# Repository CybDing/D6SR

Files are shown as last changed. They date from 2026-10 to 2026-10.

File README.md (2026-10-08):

<div align="center">

**English** | [简体中文](README.zh-CN.md)

# D6SR: A Mechanically Decoupled Six-Axis Spherical Rolling Robot

**Design and Control of D6SR: A Mechanically Decoupled Six-Axis Spherical Rolling Robot for Stable Propeller-Driven Rolling**<br>
IROS 2026

Leqi Ding\*, Xijian Deng\*, Jiayi Chen, Jin Yang, Ping Wei<br>
Xi'an Jiaotong University · \*equal contribution

Paper: coming soon · [License: Apache-2.0](LICENSE)

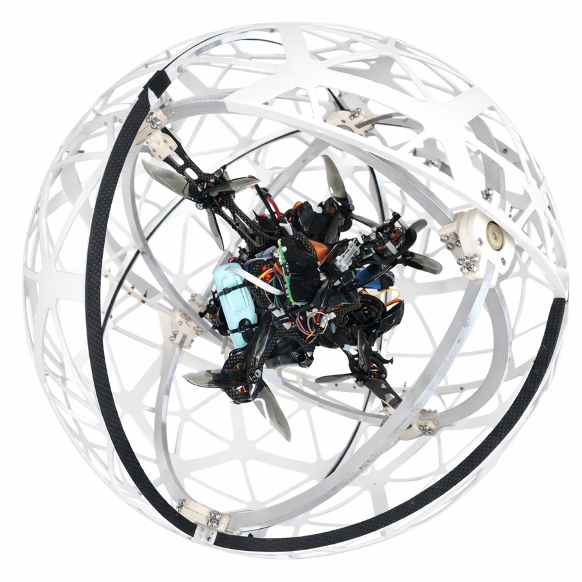
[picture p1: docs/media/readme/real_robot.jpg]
D6SR prototype


</div>

D6SR is a propeller-driven spherical robot. Six reversible propellers are mounted on an inner body, and a three-DoF gimbal decouples that body from the passive rolling shell. While the shell rolls, the inner body stays level, so every thrust direction stays fixed in the world frame and the motors do not have to keep reversing. A cascaded PID controller holds the inner-body attitude. On top of it, a residual reinforcement-learning policy, trained in simulation on IMU-only observations, adds corrective torque on rough terrain.

<p align="center">
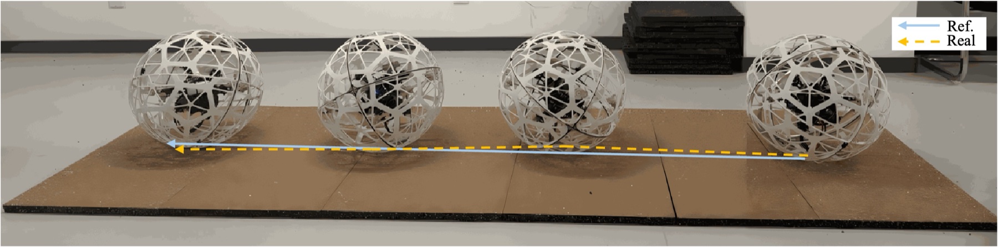
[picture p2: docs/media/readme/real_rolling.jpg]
Hardware rolling experiment
  <br>
  <em>Hardware rolling experiment: the robot keeps a straight heading (blue: reference, yellow: actual).</em>
</p>

## Contents

- [Highlights](#highlights)
- [Hardware](#hardware)
- [Method](#method)
- [Results](#results)
- [Repository structure](#repository-structure)
- [Getting started](#getting-started)
- [Reproducing the paper](#reproducing-the-paper)
- [Serial protocol](#serial-protocol)
- [Citation](#citation)
- [License](#license)

## Highlights

- **Mechanical decoupling.** A three-DoF gimbal separates shell rotation from the propulsion module, so thrust directions stay constant during rolling.
- **Tri-orthogonal six-propeller propulsion.** Three orthogonal pairs of reversible propellers can generate an arbitrary body wrench without dedicated drive motors.
- **Cascaded PID + residual RL.** A Soft Actor-Critic policy outputs only a residual torque on top of the PID baseline.
- **Calibrated simulation.** The MuJoCo model is calibrated to the prototype (per-propeller thrust, bearing friction, sensor noise, loop delay, thrust lag). The repository includes the trained policy and the scripts that regenerate every simulation figure in the paper.

## Hardware

<p align="center">
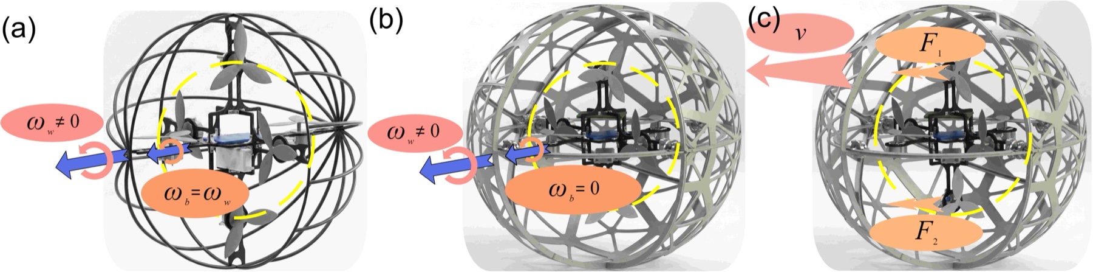
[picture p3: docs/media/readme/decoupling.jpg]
Decoupling principle
  <br>
  <em>(a) Without decoupling the inner body rotates with the shell. (b) With the gimbal it stays still while the shell rolls. (c) Thrusts F<sub>1</sub>, F<sub>2</sub> therefore stay fixed in the world frame and drive the robot at velocity v.</em>
</p>

| Item | Specification |
|---|---|
| Outer diameter / total mass | 460 mm / 2.78 kg |
| Propulsion | 6 reversible brushless motors with bidirectional ESCs, 14.7 N max thrust each |
| Controller | STM32F407VET6 (libopencm3 + FreeRTOS), cascaded PID at 100 Hz |
| Companion computer | Raspberry Pi 4B (serial bridge, logging, MQTT) |
| Attitude sensor | IMU over UART, 200 Hz |
| Link | UART 115200 bps, 8N1 |

<details>
<summary>Mechanical design</summary>
<p align="center">
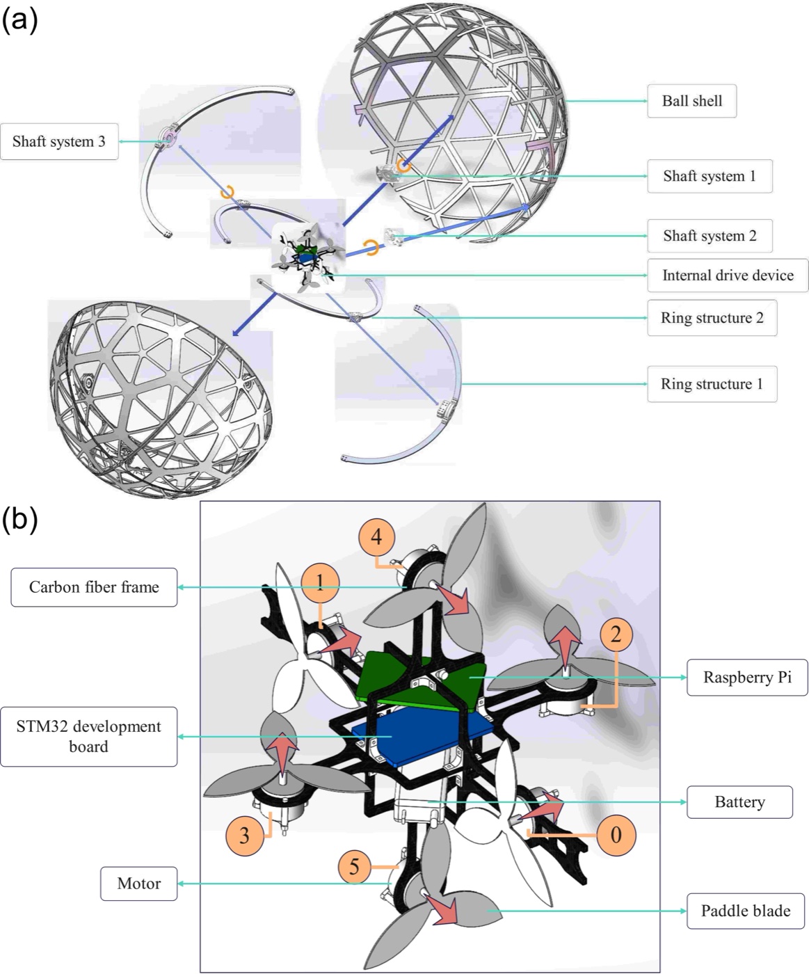
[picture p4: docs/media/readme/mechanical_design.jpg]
Mechanical design
  <br>
  <em>(a) Exploded view of the outer shell and the gimbal-based inner module. (b) Integrated six-actuator propulsion and control platform.</em>
</p>
</details>

## Method

**Attitude control.** Roll, pitch and yaw of the inner body are regulated by three cascaded PID loops: the outer loop maps angle to angular-rate setpoint, the inner loop maps rate to torque. The firmware (`stm32/cascaded_pid.c`) and the simulator (`simulation/mujoco_sim/control/cascaded_pid.py`) implement the same controller.

**Motion control.** The desired planar acceleration is rotated from the world frame into the body frame using the measured yaw, then tracked by a velocity PID.

**Control allocation.** Motors M0/M1, M2/M3 and M4/M5 form the yaw, roll and pitch pairs. The commanded wrench is mapped to signed, normalized motor thrusts and clipped to [-1, 1]. In the code and on the robot, the attitude torque of each pair is applied by raising the thrust of one motor only, rather than pushing the two motors in opposite directions. This engineering choice avoids reversing the motors just to make small attitude corrections.

**Residual RL.** The policy adds a bounded residual torque to the PID output. Each observation frame is 11-dimensional (sin/cos of roll, pitch and yaw; body rates; velocity-tracking error), and the policy input stacks the last four frames. It was trained with SAC for 400k steps, with domain randomization over gimbal initial angles, rolling friction, target velocity and terrain roughness (≤ 0.2). Full hyperparameters are in [docs/figure_reproduction.md](docs/figure_reproduction.md).

## Results

All simulation figures below come from the scripts in this repository with the released policy. PID gains were tuned, and the policy was trained, only on terrain roughness ≤ 0.2.

| Task | No attitude control | Cascaded PID | PID + residual RL |
|---|---|---|---|
| Circle, R = 10 m, 0.5 m/s, roughness 0.2 | flips, mean error 24.35 m | — | **0.55 m, no flip** |
| Straight line, 1.0 m/s, roughness 0.3: flips in 5 runs | 5 / 5 | 3 / 5 | **0 / 5** |

<table>
  <tr>
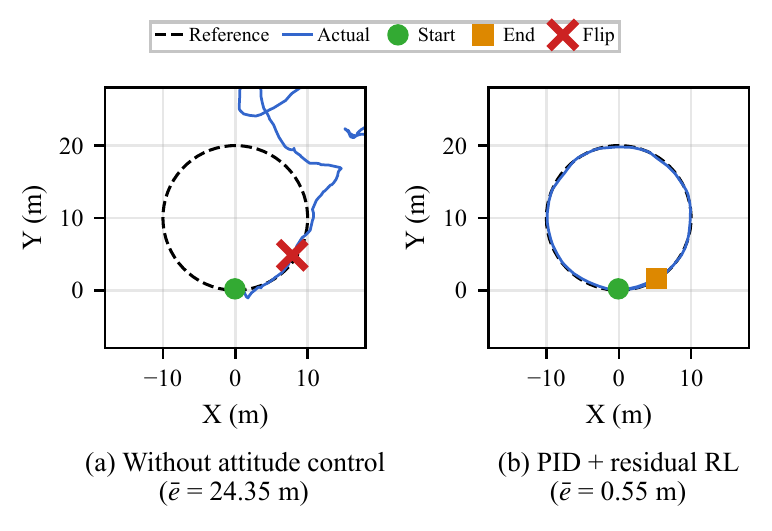
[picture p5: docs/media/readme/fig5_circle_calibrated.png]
Circle tracking
    <td align="center" width="50%"><br><em>Circular rolling on roughness 0.2.</em></td>
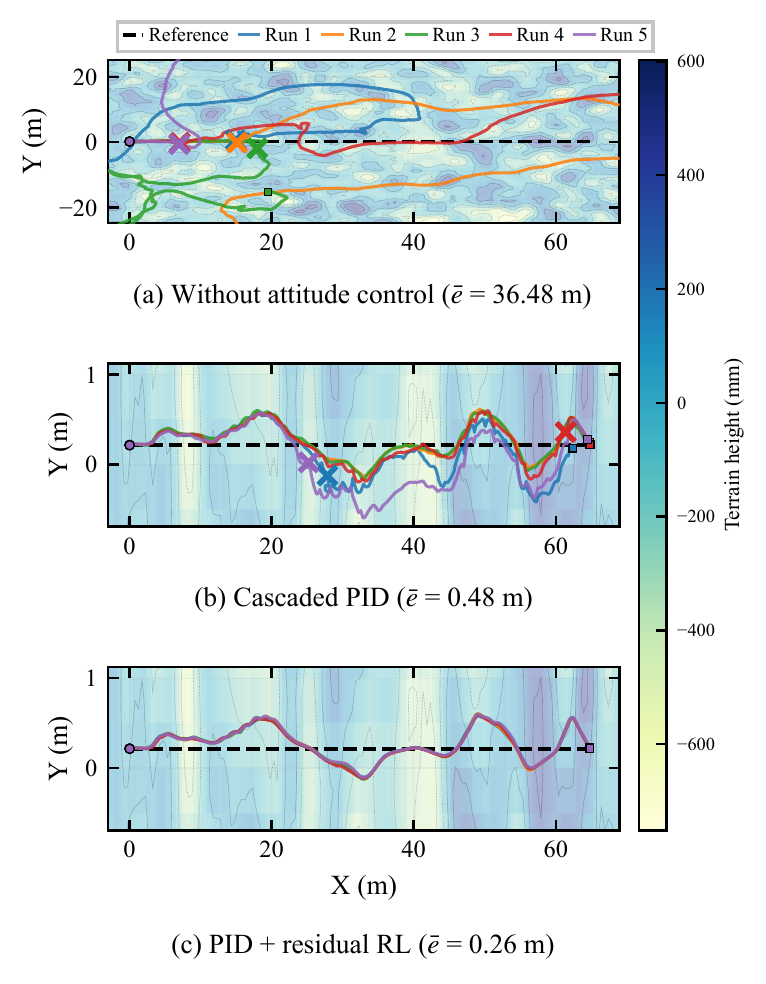
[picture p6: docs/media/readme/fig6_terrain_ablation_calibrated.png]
Straight-line terrain test
    <td align="center" width="50%"><br><em>Straight-line rolling on roughness 0.3, five runs per controller. × marks a flip.</em></td>
  </tr>
  <tr>
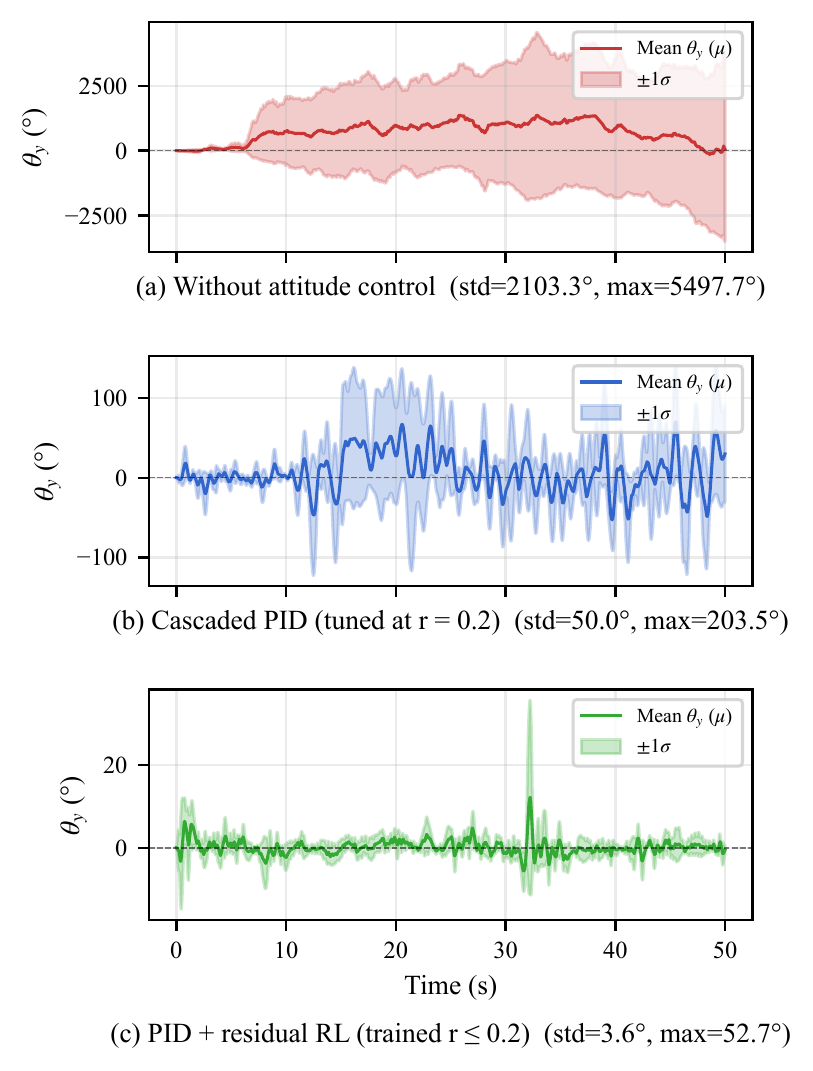
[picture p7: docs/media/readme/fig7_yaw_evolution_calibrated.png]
Yaw evolution
    <td align="center"><br><em>Inner-body yaw on roughness 0.3 (mean ± 1σ over 4 runs).</em></td>
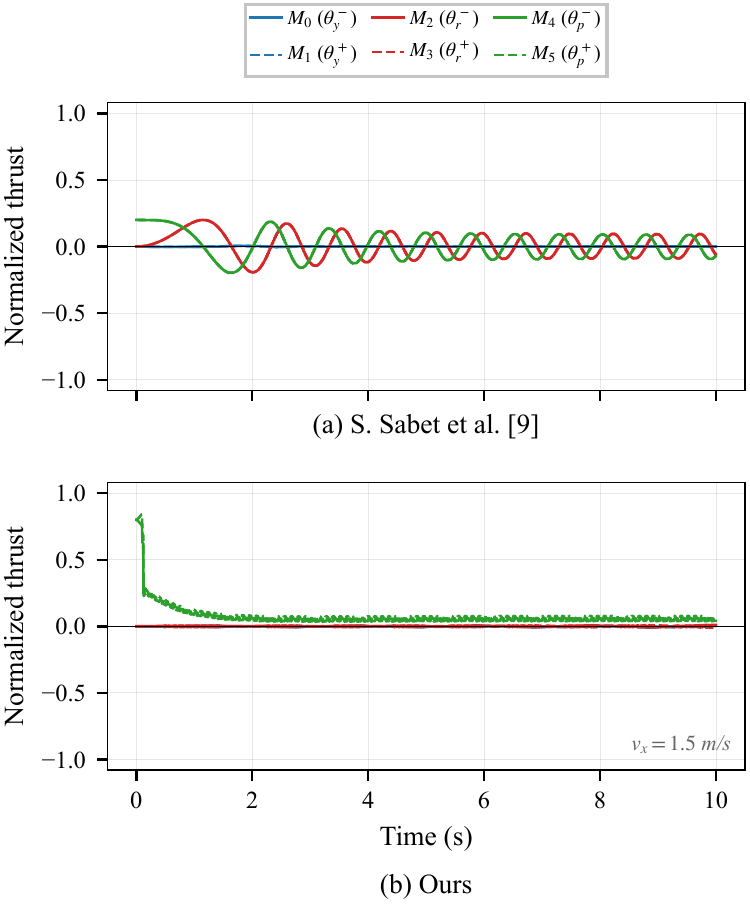
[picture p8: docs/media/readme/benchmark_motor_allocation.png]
Motor allocation
    <td align="center"><br><em>Motor commands at v<sub>x</sub> = 1.5 m/s: (a) shell-fixed propellers (Rollocopter, Sabet et al.) keep reallocating thrust; (b) D6SR holds nearly constant thrust.</em></td>
  </tr>
</table>

<p align="center">
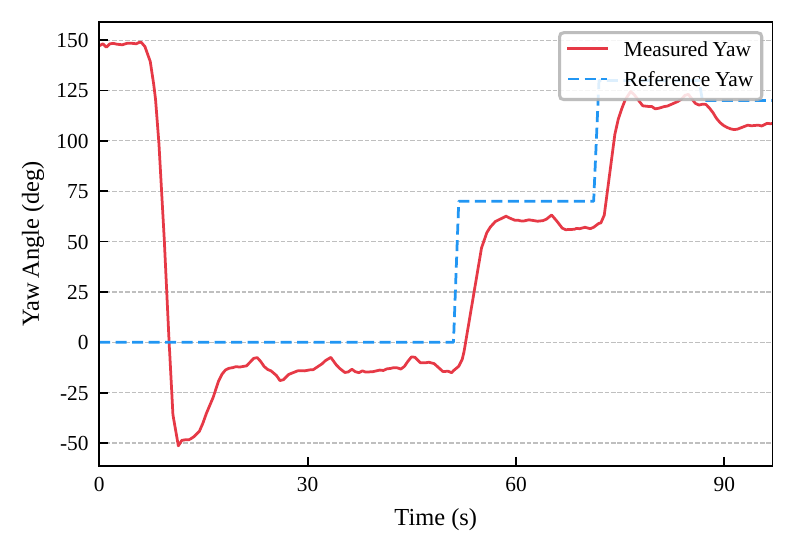
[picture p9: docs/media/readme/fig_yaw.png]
Hardware yaw step response
  <br>
  <em>Hardware: yaw stabilization during rolling under step reference commands.</em>
</p>

## Repository structure

```
D6SR/
├── stm32/                     # STM32F407 firmware: FreeRTOS tasks, cascaded PID, PWM, IMU, UART
├── raspberry_pi/              # host program: serial bridge, MQTT, logging and plotting
├── simulation/
│   ├── mujoco_sim/
│   │   ├── simulation.py      # RobotSimulation: model build, contact, rolling friction, IMU
│   │   ├── config/            # robot_params.yaml, calibrated plant, tuned PID gains
│   │   ├── control/           # cascaded PID, allocation, baseline controller, trajectories
│   │   ├── rl/                # Gym-style env, SAC, residual training; released policy in rl/checkpoints/
│   │   ├── analysis/          # scripts for paper Figs. 5-7 and PID tuning
│   │   ├── benchmark_*.py     # benchmark scripts (benchmark_baseline.py -> Fig. 8)
│   │   └── video/             # scenario recording
│   ├── robot_v0/, robot_v1/   # URDF + meshes (v0: shell-fixed baseline, v1: D6SR)
├── docs/                      # figure_reproduction.md, figures
├── data/                      # hardware yaw data behind Fig. 9
├── tools/                     # yaw PID tuning and figure-data utilities
├── libopencm3/                # submodule
└── rtos/FreeRTOS-Kernel/      # submodule
```

## Getting started

### Simulation

Python ≥ 3.9:

```bash
git clone --recursive https://github.com/CybDing/D6SR.git
cd D6SR/simulation/mujoco_sim
pip install mujoco numpy scipy matplotlib pyyaml torch

# baseline attitude stabilization + velocity drive (headless, with plots)
python control/run_baseline.py --plot --drive-x 0.5
```

Run every script from `simulation/mujoco_sim/`. On macOS, the interactive viewer needs `mjpython` (e.g. `mjpython control/run_baseline.py --no-headless`). Physics parameters live in `config/robot_params.yaml`; after editing them, regenerate the MJCF with `python robot_loader.py`.

### Firmware

Requirements: `arm-none-eabi-gcc` ≥ 10, `make`, `st-flash` (stlink-tools).

```bash
git submodule update --init --recursive    # if not cloned with --recursive
make -C libopencm3 TARGETS=stm32/f4         # once

cd stm32
make                 # build
make f407-program    # clean rebuild + flash
make monitor         # serial console (minicom, /dev/ttyUSB0, 115200)
```

Pin, timer and UART assignments are in `stm32/pin_config.h`.

### Host (Raspberry Pi)

```bash
cd raspberry_pi
pip3 install -r requirements.txt
python3 main.py          # serial + MQTT + logging + plotting
python3 simple_test.py   # connectivity check
```

## Reproducing the paper

Run from `simulation/mujoco_sim/` with `P=rl/checkpoints/calib_v7b_nojoint_fs4/best.pt`:

| Figure | Command |
|---|---|
| Fig. 5 circle | `python analysis/fig_circle.py --policy $P` |
| Fig. 6 terrain | `python analysis/fig6_ablation.py --policy $P` |
| Fig. 7 yaw | `python analysis/fig_paper_yaw.py --policy $P` |
| Fig. 8 allocation | `python benchmark_baseline.py --no-rl` |

Seeds are fixed, so the reruns reproduce the published numbers exactly. [docs/figure_reproduction.md](docs/figure_reproduction.md) (in Chinese) lists the expected values for each figure, the PID-tuning and RL-training commands, a table mapping the paper's hyperparameters to code arguments, and the places where the implementation differs from the paper's wording. Fig. 9 is a hardware experiment; its data, recovered from the vector figure, is in `data/fig9_yaw_hardware.csv`.

## Serial protocol

Frames are `CMD:DATA1,DATA2,...\n` over UART at 115200 bps, 8N1.

| Command | Format | Direction | Meaning |
|---|---|---|---|
| `PWM` | `PWM:m0,m1,m2,m3,m4,m5` | Pi → STM32 | set the six motor pulses, 1000–2000 µs, 1500 = neutral |
| `PID` | `PID:kp,ki,kd` | Pi → STM32 | update PID gains |
| `IMU` | `IMU` → `IMU:ax,ay,az,gx,gy,gz,roll,pitch,yaw` | both | request / return IMU data |
| `STATUS` | `STATUS` → `STATUS:motor,imu,pid` | both | subsystem status |
| `DEBUG` | `DEBUG:message` | STM32 → Pi | debug message |

## Citation

```bibtex
@inproceedings{ding2026d6sr,
  title     = {Design and Control of {D6SR}: A Mechanically Decoupled Six-Axis Spherical Rolling Robot for Stable Propeller-Driven Rolling},
  author    = {Ding, Leqi and Deng, Xijian and Chen, Jiayi and Yang, Jin and Wei, Ping},
  booktitle = {2026 IEEE/RSJ International Conference on Intelligent Robots and Systems (IROS)},
  year      = {2026}
}
```

## License

The code in this repository is released under the [Apache License 2.0](LICENSE). The third-party submodules keep their own licenses: `libopencm3/` (LGPL-3.0) and `rtos/FreeRTOS-Kernel/` (MIT).

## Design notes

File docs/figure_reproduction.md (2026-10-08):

# 论文插图复现说明

记录论文 *Design and Control of D6SR* 中图 5–9 的生成方式：用哪个脚本、哪个 checkpoint、期望得到什么数值。所有仿真图的随机种子均已固定，因此重跑应当逐位复现，下表的「校验数值」就是用来确认这一点的——跑完对不上，说明参数或 checkpoint 用错了。

## 通用前提

- 全部命令从 `simulation/mujoco_sim/` 目录执行（相对路径依赖此工作目录）。
- 无需 `mjpython`：这些都是 headless 出图，用 `python` 即可（`mjpython` 只在需要交互式 viewer 时才必要）。
- 物理参数来自 `config/robot_params.yaml`，PID 增益来自 `config/tuned_gains_calibrated.json`（脚本默认值），均无需手动指定。
- 图 5/6/7 的排版（字体、子图标签）统一由 `simulation/mujoco_sim/paper_style.py` 提供，不要在各脚本里另写 rcParams。

## 图 5–8

| 图 | 命令（在 `simulation/mujoco_sim/` 下） | 输出 | 校验数值 |
|---|---|---|---|
| 5 | `python analysis/fig_circle.py --policy rl/checkpoints/calib_v7b_nojoint_fs4/best.pt` | `docs/media/fig5_circle_calibrated.pdf` | (a) mean err 24.35 m；(b) 0.55 m |
| 6 | `python analysis/fig6_ablation.py --policy rl/checkpoints/calib_v7b_nojoint_fs4/best.pt` | `docs/media/fig6_terrain_ablation_calibrated.pdf` | tier means 36.48 / 0.48 / 0.26 m |
| 7 | `python analysis/fig_paper_yaw.py --policy rl/checkpoints/calib_v7b_nojoint_fs4/best.pt` | `docs/media/fig7_yaw_evolution_calibrated.pdf` | (a) std 2103.3°；(b) std 50.0°；(c) std 3.6°, max 52.7° |
| 8 | `python benchmark_baseline.py --no-rl` | 见下方「图 8 的额外拷贝步骤」 | V0 travel +10.96 m；V1 travel +14.79 m |

### 图 7 的 policy 选择（重要）

图 5、6、7 **统一使用 `calib_v7b_nojoint_fs4`**。

早期提交的图 7 用的是 `calib_v6_fs4`，(c) 档得到 std = 4.3°、max = 44.4°；换成与图 5/6 相同的 `calib_v7b_nojoint_fs4` 后为 **std = 3.6°、max = 52.7°**。三张图现已统一到同一个 policy，论文正文中引用图 7 的数值需与此一致。

注意 (a)、(b) 两档不含 RL，与 policy 无关，无论用哪个 checkpoint 都复现为 std 2103.3° / 50.0°。**因此 policy 用错只会在 (c) 档暴露**，(a)(b) 对得上并不能说明命令正确。

### 图 8 的额外拷贝步骤

`benchmark_baseline.py` 把 PDF 写到脚本自身目录，而 `.gitignore` 忽略 `*.pdf`、只放行 `docs/media/**`，所以纳入版本管理的是 `docs/media/` 下那一份，需手动拷贝：

```bash
python benchmark_baseline.py --no-rl
cp benchmark_motor_allocation.pdf ../../docs/media/benchmark_motor_allocation.pdf
```

`--no-rl` 决定了图中只有 (a)、(b) 两个面板；去掉该参数会额外生成 PID-only 与 PID+RL 面板。

## 图 9（硬件）——不可重跑

图 9 是实机 yaw 阶跃响应，不是仿真结果，仓库中没有生成它的脚本。

**原始树莓派日志从未落盘**：`raspberry_pi/main.py` 的 `_plot_yaw_cascaded()` 只调用 `plt.savefig` 输出 PNG 到 `raspberry_pi/plots/`（该目录只存在于树莓派上），`data_dict` 中的数组从未序列化，git 也从未跟踪过。因此不存在可供找回的日志，重跑也需要实体机器人。

现存物：

- `docs/media/fig_yaw.pdf` —— 图 9 本体（矢量 PDF，投稿时所用）。
- `data/fig9_yaw_hardware.csv` —— 从该 PDF 中还原出的数据，156 行 `time_s, measured_yaw_deg, reference_yaw_deg`。
- `tools/extract_fig_yaw_data.py` —— 还原脚本，可重跑复核：

```bash
python tools/extract_fig_yaw_data.py
```

还原是**精确复原而非估读**：坐标轴刻度给出闭式线性映射（残差 ~1e-7 pt），并有两个独立校验位——参考阶跃还原为精确整数（0 → 70 → 130 → 120 度），156 个测量点全部落在 0.1° 的 IMU 网格上（偏差 ~1e-5）。数值已 snap 回上述网格以消除 PDF 六位小数的往返误差。

两点需知：

- 参考信号在 t ≈ 72–86 s 有一档 **130°**，在原图中被图例框完全遮挡，肉眼不可见；矢量还原把它取了出来。实际是四档而非三档。
- 时间戳为不规则墙钟时间（中位 0.51 s），且 matplotlib 的 path-simplification 在当年渲染时丢弃了约 2% 的近似共线采样点——这部分 PDF 里根本没有，无法恢复。故该 CSV 是**图上所绘的曲线**，而非完整原始日志。

## 控制器与训练配置（对照论文 Table I / II）

### 仿真平台（论文 Table I）

| 论文参数 | 值 | 代码位置 |
|---|---|---|
| MuJoCo timestep | 0.001 s | `config/robot_params.yaml` |
| 控制频率（PID / RL） | 50 Hz | `SphericalRobotEnv(pid_rate=50)`，每个控制周期 20 个物理步 |
| 滚动摩擦 μ_roll | 0.01 | `SphericalRobotEnv(mu_roll=0.01)` |
| 单桨最大推力 | 14.7 N | `config/realistic_config.json` → `force_max` |
| 总质量 | 2.78 kg | `realistic_config.json` 的 `mass_overrides`（仿真内合计 2.785 kg） |
| 轴承摩擦 | 0.01 N·m | `realistic_config.json` → `joint_frictionloss`（另有 `joint_damping` 0.002） |
| 姿态 / 陀螺噪声 | 0.5° / 0.02 rad/s | realism pack，`--realism` |
| 控制回路延迟 | 20 ms（一个周期） | realism pack，`imu_delay_steps=1` |
| 推力一阶滞后 | 80 ms | realism pack，`thrust_tau=0.08` |

### PID 整定

`config/tuned_gains_calibrated.json` 是在标定后的 plant 上、开启 realism、r = 0.2 地形下用坐标下降整定得到的增益，图 5–7 与 RL 训练都使用它：

```bash
python analysis/tune_pid.py --realism --roughness 0.2 --out config/tuned_gains_calibrated.json
```

### 残差 RL 训练（论文 Table II）

论文所用 policy 为 `rl/checkpoints/calib_v7b_nojoint_fs4/best.pt`（仓库中仅保留此文件）。训练命令：

```bash
python rl/train_residual.py --unidirectional --no-joint-obs \
  --sim-config-json config/realistic_config.json \
  --gains-json config/tuned_gains_calibrated.json \
  --ckpt-subdir calib_v7b_nojoint_fs4 \
  --yaw-reward 4 --act-penalty 1 --smooth-penalty 0.5 \
  --target-entropy -6 --init-alpha 0.05 --alpha-max 0.05 \
  --realism --frame-stack 4 --total-steps 400000
```

目标速度按论文在每个 episode 开始时从 U[-1, 1] m/s 随机采样（不加 `--fixed-drive`）。

| 论文参数 | 值 | 对应参数 / 默认值 |
|---|---|---|
| 总训练步数 | 400,000 | `--total-steps 400000` |
| Episode 长度 | 500 | `--episode-steps`（默认 500） |
| Replay buffer | 500,000 | `--buffer-size`（默认） |
| Batch size | 128 | `--batch-size`（默认） |
| "Target update interval" 2 | 2 | 实为 `--utd-ratio 2`：每个环境步做 2 次 critic 更新，每次 critic 更新后都对 target 做一次 τ = 0.005 的软更新；actor 与熵系数 α 每步只更新 1 次 |
| Actor / Critic / Entropy 学习率 | 3e-4 / 1e-4 / 3e-4 | `--lr-actor` / `--lr-critic`（默认），`lr_alpha` 写死为 3e-4 |
| γ / τ | 0.99 / 0.005 | `rl/sac.py` 默认值 |
| 隐层 | (128, 128) | `train_residual.py` 写死 |
| 观测维度 | 11 × 4 | `--no-joint-obs --frame-stack 4`（obs_dim = 44） |
| Target entropy | −6 | `--target-entropy -6` |
| 残差比例 β | 论文未给数值 | `--alpha-max 0.05` |
| 奖励系数 | 4 / 0.5 / 1.0 / 0.5 / +0.5,−10 | roll·pitch 的 4 写死在 `env.py`，yaw 的 4 来自 `--yaw-reward 4`；`--act-penalty 1`、`--smooth-penalty 0.5` |
| Warm-up | 前 5,000 步零残差 | `--warmup-random 5000`（默认） |
| 域随机化 | 关节初值 ±0.3 rad，μ_roll ×[0.5, 1.5]，p = 0.5 时 r ~ U[0.05, 0.2] | `env.py` 中 `randomize=True`；`--terrain-prob 0.5 --roughness-min 0.05 --roughness-max 0.2`（默认） |

`best.pt` 是训练过程中定期评估得分最高的快照（训练步 165,001），不是第 400k 步的最终权重。

### 代码实现与论文写法的差异

- **姿态环的 T_b(θ) 变换**：论文公式中外环输出的欧拉角速率经 T_b(θ) 变换为体坐标系角速度后再进入内环。图 5–7 与 RL 训练实际使用的是三轴独立的串级 PID（`BaselineController(euler_rate_transform=False)`，默认值），即小姿态角下 T_b ≈ I 的近似。带变换的实现已提供，可通过 `euler_rate_transform=True` / `control/run_baseline.py --euler-rate-transform` 开启，但开启后增益需要重新整定，论文图也不再逐位复现。
- **单向电机混控**：训练与图 5–7 使用 `unidirectional=True` 的混控（`control/run_baseline.py::mix_motors`）：每对电机产生姿态力矩时只增加一侧电机的推力，而不是像论文闭式分配 A(f̃, τ̃) 那样让两侧对称地一正一反。这是工程上的限制，用来避免为了姿态微调而频繁反转电机，真机也采用同样的做法。图 8（`benchmark_baseline.py`）使用的是论文中的双向对称分配。

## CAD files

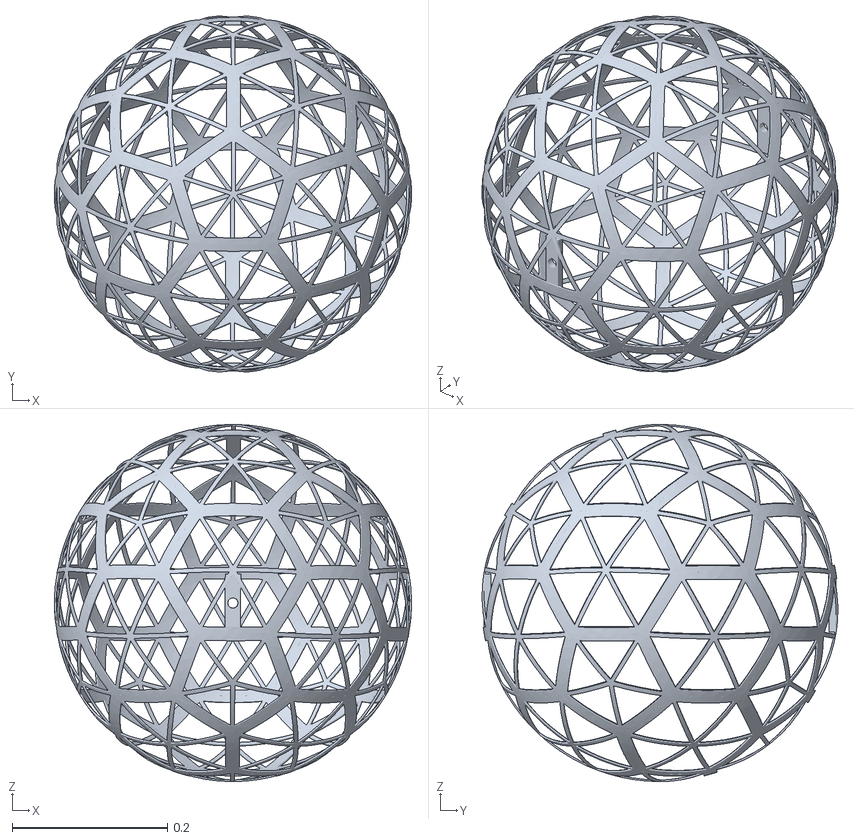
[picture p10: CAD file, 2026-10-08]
simulation/robot_v1/meshes/Link3.STL
0.46 x 0.458 x 0.46

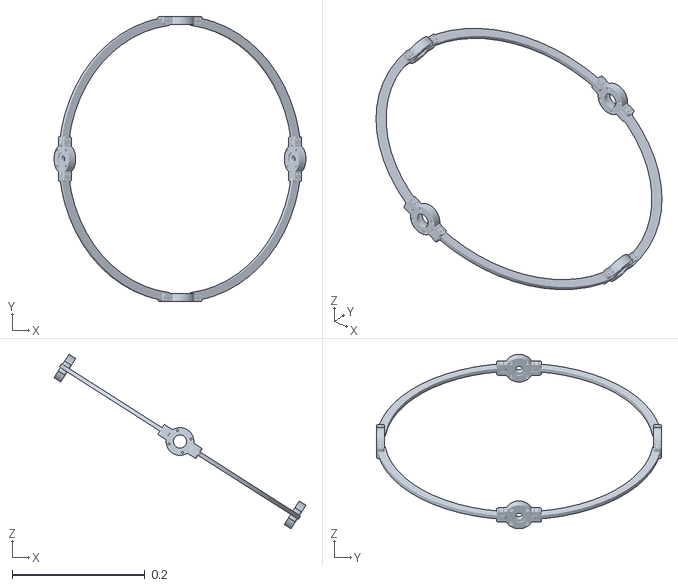
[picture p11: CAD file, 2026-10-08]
simulation/robot_v1/meshes/Link2.STL
0.38 x 0.43 x 0.263

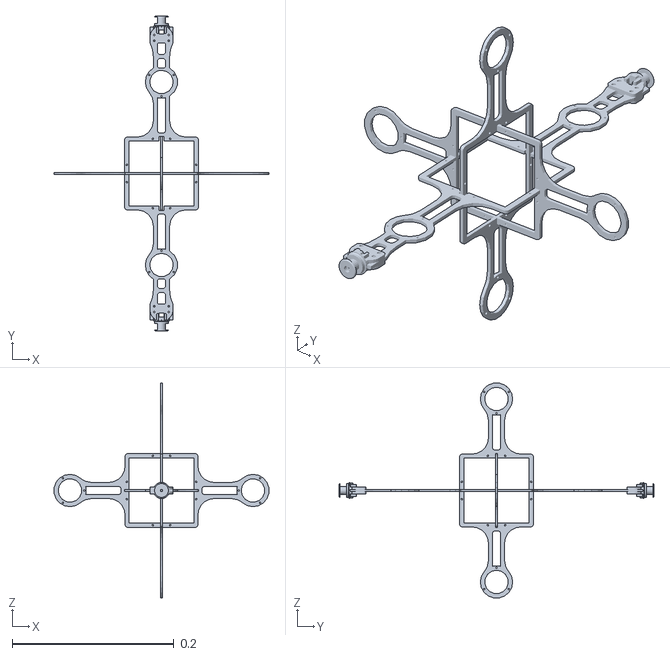
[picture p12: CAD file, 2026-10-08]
simulation/robot_v1/meshes/base_link.STL
0.265 x 0.389 x 0.265

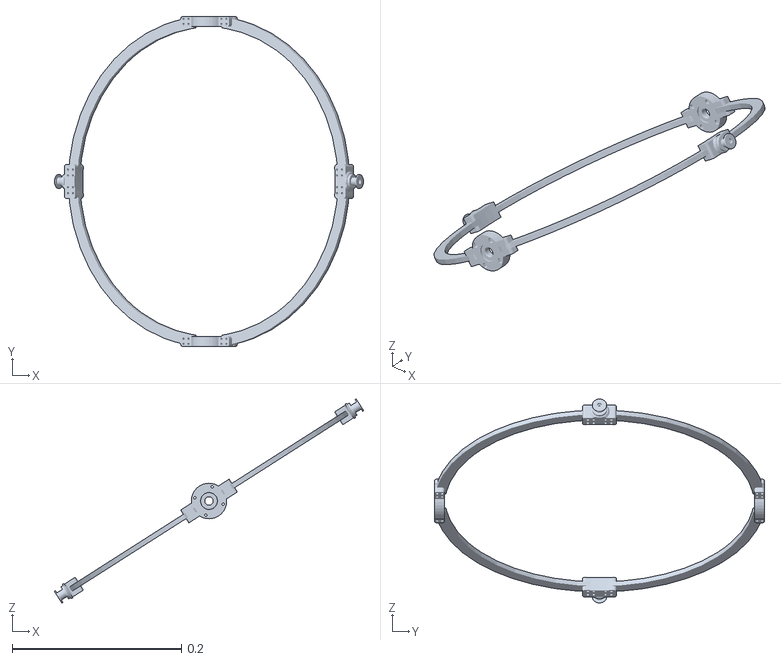
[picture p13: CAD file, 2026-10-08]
simulation/robot_v1/meshes/Link1.STL
0.365 x 0.39 x 0.241

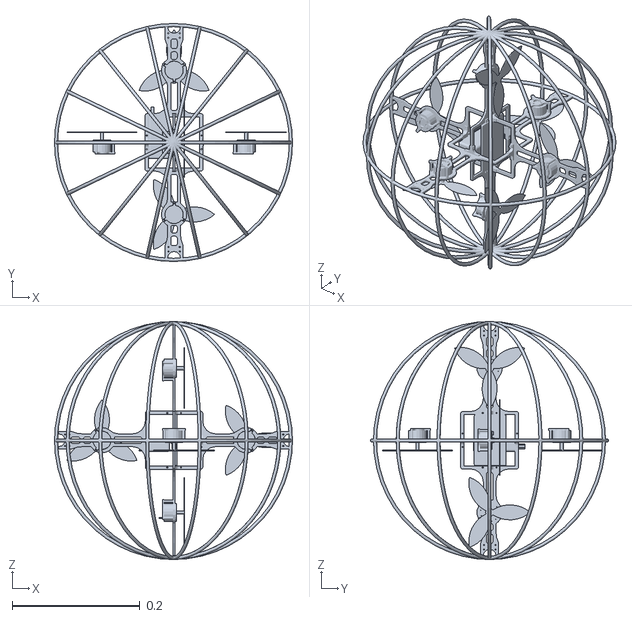
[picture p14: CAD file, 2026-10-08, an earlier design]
simulation/robot_v0/meshes/base_link.STL
0.373 x 0.373 x 0.373

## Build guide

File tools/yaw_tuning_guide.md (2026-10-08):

# Yaw轴双环PID调节指南

## 🎯 调节目标
从零开始调节Yaw轴的双环级联PID控制器，使其能够稳定保持目标角度。

## 📐 系统架构
- **外环(位置环)**: 角度误差 → 速度目标 (°/s)
- **内环(速度环)**: 速度误差 → PWM增量
- **电机**: M0(负向), M1(正向), 基准PWM=1550

## 🔧 调节步骤

### 阶段1: 内环速度环调节 (重点!)

**目标**: 让速度环能够准确、稳定地跟踪目标速度，无超调、无震荡

#### 1.1 准备工作
```bash
# 1. 编译并烧录代码
cd stm32/
make flash

# 2. 打开串口监控
make monitor
# 或使用: screen /dev/ttyUSB0 115200
```

#### 1.2 使能调试输出
在串口终端发送:
```
ZDEBUG:1      # 开启Yaw调试输出
ZSTAB:1       # 开启Yaw双环PID控制器
```

#### 1.3 内环Kp调节 (先只调Kp)

**初始参数**:
- inner_kp = 0.5 (从小开始)
- inner_ki = 0.0 (暂时关闭)
- inner_kd = 0.0 (暂时关闭)
- outer_kp = 0.0 (外环暂时关闭)
- outer_ki = 0.0
- outer_kd = 0.0

**测试方法**: 修改cascaded_pid.c，在cascaded_pid_step()函数中强制设置速度目标
```c
// 在cascaded_pid.c的cascaded_pid_step()函数中
// 找到"外环输出: 速度目标"这一行之后，添加:
ctrl->velocity_target = 30.0f;  // 强制设置30°/s的速度目标
```

**调节步骤**:
1. 设置 inner_kp = 0.5，编译烧录
2. 观察调试输出中的 `v_fb` (实际速度) 和 `vtgt` (目标速度=30)
3. 如果 v_fb 远小于 vtgt (比如只有10°/s)，说明Kp太小，增大到0.8
4. 继续增大Kp，直到速度能够接近目标值 (允许±5°/s误差)
5. 如果出现震荡，说明Kp过大，减小10%

**期望结果**: v_fb稳定在25-35°/s范围内，无明显震荡

**参考范围**: inner_kp = 0.5 ~ 1.5

---

#### 1.4 内环Ki调节 (消除稳态误差)

**当前状态**: Kp已调好，但可能存在稳态误差(比如目标30，实际稳定在26)

**调节步骤**:
1. 设置 inner_ki = 0.05，保持Kp不变
2. 观察 v_fb 是否更接近 vtgt
3. 如果稳态误差仍然存在，增大Ki到0.1
4. 如果出现震荡或超调，减小Ki
5. 最终使 v_fb 稳定在 vtgt±2°/s 范围内

**期望结果**: v_fb = 30±2°/s，无震荡，无超调

**参考范围**: inner_ki = 0.05 ~ 0.2

---

#### 1.5 内环Kd调节 (可选，抑制速度噪声)

**注意**: 速度环的Kd通常很小，因为速度本身已经是微分量

**调节步骤**:
1. 设置 inner_kd = 0.02
2. 观察PWM输出(M0/M1)是否更平滑
3. 如果速度响应变慢，减小Kd
4. 如果PWM抖动严重，可以增大Kd到0.05

**期望结果**: PWM输出平滑，速度跟踪稳定

**参考范围**: inner_kd = 0.02 ~ 0.08

---

#### 1.6 验证内环性能

**测试不同速度目标**:
```c
// 修改velocity_target测试不同值
ctrl->velocity_target = 10.0f;   // 测试小速度
ctrl->velocity_target = 30.0f;   // 测试中速度
ctrl->velocity_target = 50.0f;   // 测试大速度
ctrl->velocity_target = -30.0f;  // 测试反向
```

**检查指标**:
- 响应时间: 0.5-1秒内达到目标速度
- 超调量: < 10%
- 稳态误差: < 5%
- 无持续震荡

---

### 阶段2: 外环位置环调节

**前提**: 内环速度环已调好！

#### 2.1 移除速度强制设置

删除或注释掉之前添加的强制速度目标代码:
```c
// ctrl->velocity_target = 30.0f;  // 删除这行!!!
```

现在velocity_target由外环PID计算得出。

#### 2.2 外环Kp调节

**初始参数**:
- outer_kp = 1.0 (从中等值开始)
- outer_ki = 0.0
- outer_kd = 0.0
- 保持内环参数不变

**测试方法**: 设置目标角度
```bash
# 在串口发送 (假设当前角度在0°附近)
STABLE:yaw:90    # 设置目标角度为90°
```

或者修改代码设置:
```c
// 在main.c的yaw_control_task()开始时添加:
cascaded_pid_set_target_angle(&g_yaw_cascaded_pid, 90.0f);
```

**调节步骤**:
1. 设置 outer_kp = 1.0
2. 观察调试输出的 `ang` (当前角度) 和 `tgt` (目标角度90)
3. 观察收敛速度:
   - 如果收敛太慢(>5秒)，增大Kp到1.5
   - 如果震荡明显，减小Kp到0.7
4. 最终使角度能在2-3秒内到达目标±10°范围

**期望结果**: 角度在2-3秒内接近目标，允许轻微震荡

**参考范围**: outer_kp = 0.8 ~ 2.0

---

#### 2.3 外环Kd调节 (抑制震荡)

**当前状态**: Kp调好后，可能出现小幅度震荡

**调节步骤**:
1. 设置 outer_kd = outer_kp / 10 (经验公式)
   - 比如 outer_kp=1.5，则 outer_kd=0.15
2. 观察震荡是否减小
3. 如果震荡仍然明显，增大Kd
4. 如果响应变慢，减小Kd

**期望结果**: 震荡幅度减小，快速收敛到目标

**参考范围**: outer_kd = 0.1 ~ 0.3

---

#### 2.4 外环Ki调节 (消除静差)

**当前状态**: 角度可能稳定在88°而不是90°(静差2°)

**调节步骤**:
1. 设置 outer_ki = 0.05
2. 观察 aerr (角度误差) 是否逐渐减小到0
3. 如果静差消除太慢，增大Ki到0.08
4. 如果出现积分饱和(突然大幅震荡)，减小Ki

**注意**:
- 死区设置为3°,所以误差<3°时积分会衰减
- 可以调整outer_deadband参数改变死区大小

**期望结果**: 最终稳定在目标角度±2°范围内

**参考范围**: outer_ki = 0.02 ~ 0.1

---

### 阶段3: 综合测试

#### 3.1 大角度测试
```bash
STABLE:yaw:0      # 回到0°
STABLE:yaw:180    # 转到180°
STABLE:yaw:270    # 转到270°
STABLE:yaw:0      # 回到0°
```

#### 3.2 小角度微调测试
```bash
STABLE:yaw:10
STABLE:yaw:15
STABLE:yaw:20
```

#### 3.3 抗干扰测试
- 手动转动机器人内部机构
- 观察是否能快速恢复到目标角度

---

## 📊 调试输出解读

```
Yaw-Cascade: ang=45.2, tgt=90.0, aerr=44.8, v_fb=25.3, vtgt=44.8, verr=19.5, delta=15, M0=1535, M1=1565
```

各字段含义:
- `ang`: 当前角度 (45.2°)
- `tgt`: 目标角度 (90.0°)
- `aerr`: 角度误差 (44.8°)
- `v_fb`: 当前角速度 (25.3°/s)
- `vtgt`: 外环输出的速度目标 (44.8°/s)
- `verr`: 速度误差 (19.5°/s)
- `delta`: 内环输出的PWM增量 (15)
- `M0/M1`: 两个电机的实际PWM值

---

## 🛠️ 参数保存

调节完成后，将参数写入 [motor_calibration.c](stm32/motor_calibration.c:116-137):

```c
const CascadedPIDConfig YAW_CASCADED_PID_CONFIG = {
    // 外环 (位置环)
    .outer_kp = 1.5f,           // 你调节的值
    .outer_ki = 0.05f,          // 你调节的值
    .outer_kd = 0.15f,          // 你调节的值
    .outer_max_output = 60.0f,  // 速度上限
    .outer_deadband = 3.0f,     // 死区

    // 内环 (速度环)
    .inner_kp = 0.8f,           // 你调节的值
    .inner_ki = 0.1f,           // 你调节的值
    .inner_kd = 0.05f,          // 你调节的值
    .inner_max_output = 100.0f, // PWM增量上限

    // 其他参数保持不变
    .dt = 0.02f,
    .base_pwm_neg = 1550,
    .base_pwm_pos = 1550,
    .delta_sign_neg = -1,
    .delta_sign_pos = +1,
    .pwm_range = 150,
};
```

---

## ⚠️ 常见问题

### Q1: 速度震荡剧烈
- 检查inner_kp是否过大
- 检查PWM_SLEW_RATE是否太小(cascaded_pid.c:24)

### Q2: 角度收敛太慢
- 增大outer_kp
- 检查outer_max_output是否太小(当前60°/s)
- 检查inner环是否调好

### Q3: 角度震荡不停
- 减小outer_kp
- 增大outer_kd
- 减小outer_ki

### Q4: 存在静差(比如目标90°,实际88°)
- 增大outer_ki
- 检查outer_deadband是否太大

### Q5: 调试输出看不到
- 确认发送了 `ZDEBUG:1`
- 检查串口波特率是否115200
- 检查DEBUG_OUTPUT_DIVIDER分频(cascaded_pid.c:33)

---

## 📝 调节记录模板

建议记录每次测试的参数和效果:

```
测试1:
inner_kp=0.5, inner_ki=0, inner_kd=0
vtgt=30, v_fb=18 → Kp太小

测试2:
inner_kp=0.8, inner_ki=0, inner_kd=0
vtgt=30, v_fb=28 → 接近目标，继续

测试3:
inner_kp=0.8, inner_ki=0.1, inner_kd=0
vtgt=30, v_fb=30 → 完美!

...
```

---

## 🎓 调节原理

**为什么先调内环?**
- 内环是外环的执行器
- 如果内环不稳定,外环无法正常工作
- 就像汽车方向盘坏了,再好的导航也没用

**Kp/Ki/Kd的作用**
- Kp: 响应速度 (误差越大,控制量越大)
- Ki: 消除静差 (累积误差,最终消除偏差)
- Kd: 抑制震荡 (预测趋势,提前减速)

**双环PID的优势**
- 分层控制,各司其职
- 内环保证执行力,外环保证准确性
- 大角度调整时更平滑(不会突然猛转)

---

祝调节顺利! 🚀

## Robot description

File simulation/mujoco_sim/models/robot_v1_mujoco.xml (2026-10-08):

<?xml version='1.0' encoding='utf-8'?>
<mujoco model="robot_v1">
  <compiler angle="radian" meshdir="../../robot_v1/meshes" />
  <asset>
    <mesh name="base_link" file="base_link.STL" />
    <mesh name="Link1" file="Link1.STL" />
    <mesh name="Link2" file="Link2.STL" />
    <mesh name="Link3" file="Link3.STL" />
  </asset>
  <worldbody>
    <geom name="ground" type="plane" size="10 10 0.1" rgba="0.92 0.9 0.86 1.0" pos="0 0 -0.5" friction="1.0 0.02 0.001" condim="6" solref="0.02 1" solimp="0.9 0.95 0.01" contype="1" conaffinity="1" />
    <body name="base_link" pos="0 0 0.3">
      <freejoint name="base_freejoint" />
      <inertial pos="2.32312122628482E-05 -6.93889390390723E-17 0.00149660321293572" mass="0.0881712091132188" diaginertia="0.000483936285114512 0.000280418522330968 0.000484748259250526" />
      <geom type="mesh" mesh="base_link" rgba="0.55 0.62 0.7 1.0" contype="0" conaffinity="0" />
      <body name="Link1" pos="3.5945E-05 -0.195 0.0015" euler="0 0 0">
        <joint name="joint1" type="hinge" limited="false" axis="0 -1 0" damping="0.0005" frictionloss="0.0002" armature="0.0003" />
        <inertial pos="1.02581138028413E-13 0.195000000000013 7.33484719490702E-14" mass="0.28315394752081" diaginertia="0.00406022994183874 0.000635822702847486 0.00432466337088171" />
        <geom type="mesh" mesh="Link1" rgba="0.9 0.55 0.2 1.0" contype="0" conaffinity="0" />
        <body name="Link2" pos="-0.17878 0.195 -0.11393" euler="0 0 -3.1416">
          <joint name="joint2" type="hinge" limited="false" axis="-0.84332 0 0.53742" damping="0.0005" frictionloss="0.0002" armature="0.0003" />
          <inertial pos="-0.178782967144676 2.00946898010201E-13 0.113932658438872" mass="0.301442340403242" diaginertia="0.00101703966013663 0.000795350839296753 0.00134656966350589" />
          <geom type="mesh" mesh="Link2" rgba="0.25 0.7 0.55 1.0" contype="0" conaffinity="0" />
          <body name="Link3" pos="-0.17878 -0.215 0.11393" euler="0 0 3.1416">
            <joint name="joint3" type="hinge" limited="false" axis="0.00010218 -1 6.5118E-05" damping="0.0005" frictionloss="0.0002" armature="0.0003" />
            <inertial pos="-1.07070866200987E-08 -0.215126592531979 -2.89904654076014E-06" mass="0.448110435494101" diaginertia="0.00132675002235673 0.00132701949121583 0.00130432215567495" />
            <geom type="mesh" mesh="Link3" rgba="0.3 0.35 0.85 0.95" friction="1.0 0.02 0.001" condim="6" solref="0.02 1" solimp="0.9 0.95 0.01" contype="1" conaffinity="1" />
          </body>
        </body>
      </body>
      <body name="ballast" pos="0.0 0.0 -0.05">
        <geom type="sphere" size="0.02" mass="0.14" rgba="0.92 0.2 0.2 0.6" contype="0" conaffinity="0" />
      </body>
    </body>
  </worldbody>
  <option timestep="0.001" gravity="0 0 -9.81" iterations="100" tolerance="1e-6" solver="Newton" integrator="implicitfast" cone="elliptic" />
</mujoco>

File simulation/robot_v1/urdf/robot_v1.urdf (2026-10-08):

<?xml version="1.0" encoding="utf-8"?>
<!-- This URDF was automatically created by SolidWorks to URDF Exporter! Originally created by Stephen Brawner (brawner@gmail.com) 
     Commit Version: 1.6.0-4-g7f85cfe  Build Version: 1.6.7995.38578
     For more information, please see http://wiki.ros.org/sw_urdf_exporter -->
<robot name="URDF（1）.SLDASM">
  <link name="base_link">
    <inertial>
      <origin xyz="2.32312122628482E-05 -6.93889390390723E-17 0.00149660321293572" rpy="0 0 0" />
      <mass value="0.0881712091132188" />
      <inertia ixx="0.000483936285114512" ixy="-1.34434114367398E-14" ixz="-3.48071698099629E-20" iyy="0.000280418522330968" iyz="-4.89986979297274E-22" izz="0.000484748259250526" />
    </inertial>
    <visual>
      <origin xyz="0 0 0" rpy="0 0 0" />
      <geometry>
        <mesh filename="package://URDF（1）.SLDASM/meshes/base_link.STL" />
      </geometry>
      <material name="">
        <color rgba="1 1 1 1" />
      </material>
    </visual>
    <collision>
      <origin xyz="0 0 0" rpy="0 0 0" />
      <geometry>
        <mesh filename="package://URDF（1）.SLDASM/meshes/base_link.STL" />
      </geometry>
    </collision>
  </link>
  <link name="Link1">
    <inertial>
      <origin xyz="1.02581138028413E-13 0.195000000000013 7.33484719490702E-14" rpy="0 0 0" />
      <mass value="0.28315394752081" />
      <inertia ixx="0.00406022994183874" ixy="-2.62394266138913E-15" ixz="-0.000283747977355711" iyy="0.000635822702847486" iyz="-1.67178445421287E-15" izz="0.00432466337088171" />
    </inertial>
    <visual>
      <origin xyz="0 0 0" rpy="0 0 0" />
      <geometry>
        <mesh filename="package://URDF（1）.SLDASM/meshes/Link1.STL" />
      </geometry>
      <material name="">
        <color rgba="1 1 1 1" />
      </material>
    </visual>
    <collision>
      <origin xyz="0 0 0" rpy="0 0 0" />
      <geometry>
        <mesh filename="package://URDF（1）.SLDASM/meshes/Link1.STL" />
      </geometry>
    </collision>
  </link>
  <joint name="joint1" type="continuous">
    <origin xyz="3.5945E-05 -0.195 0.0015" rpy="0 0 0" />
    <parent link="base_link" />
    <child link="Link1" />
    <axis xyz="0 -1 0" />
    <limit lower="-3.14" upper="3.14" effort="100" velocity="1" />
  </joint>
  <link name="Link2">
    <inertial>
      <origin xyz="-0.178782967144676 2.00946898010201E-13 0.113932658438872" rpy="0 0 0" />
      <mass value="0.301442340403242" />
      <inertia ixx="0.00101703966013663" ixy="4.31526555208568E-18" ixz="0.00035359928686953" iyy="0.000795350839296753" iyz="-3.76870602774083E-18" izz="0.00134656966350589" />
    </inertial>
    <visual>
      <origin xyz="0 0 0" rpy="0 0 0" />
      <geometry>
        <mesh filename="package://URDF（1）.SLDASM/meshes/Link2.STL" />
      </geometry>
      <material name="">
        <color rgba="1 1 1 1" />
      </material>
    </visual>
    <collision>
      <origin xyz="0 0 0" rpy="0 0 0" />
      <geometry>
        <mesh filename="package://URDF（1）.SLDASM/meshes/Link2.STL" />
      </geometry>
    </collision>
  </link>
  <joint name="joint2" type="continuous">
    <origin xyz="-0.17878 0.195 -0.11393" rpy="0 0 -3.1416" />
    <parent link="Link1" />
    <child link="Link2" />
    <axis xyz="-0.84332 0 0.53742" />
    <limit lower="-3.14" upper="3.14" effort="100" velocity="1" />
  </joint>
  <link name="Link3">
    <inertial>
      <origin xyz="-1.07070866200987E-08 -0.215126592531979 -2.89904654076014E-06" rpy="0 0 0" />
      <mass value="0.448110435494101" />
      <inertia ixx="0.00132675002235673" ixy="-5.02834787896599E-09" ixz="-5.1597062079967E-08" iyy="0.00132701949121583" iyz="-2.20335148394562E-06" izz="0.00130432215567495" />
    </inertial>
    <visual>
      <origin xyz="0 0 0" rpy="0 0 0" />
      <geometry>
        <mesh filename="package://URDF（1）.SLDASM/meshes/Link3.STL" />
      </geometry>
      <material name="">
        <color rgba="1 1 1 1" />
      </material>
    </visual>
    <collision>
      <origin xyz="0 0 0" rpy="0 0 0" />
      <geometry>
        <mesh filename="package://URDF（1）.SLDASM/meshes/Link3.STL" />
      </geometry>
    </collision>
  </link>
  <joint name="joint3" type="continuous">
    <origin xyz="-0.17878 -0.215 0.11393" rpy="0 0 3.1416" />
    <parent link="Link2" />
    <child link="Link3" />
    <axis xyz="0.00010218 -1 6.5118E-05" />
    <limit lower="-3.14" upper="3.14" effort="100" velocity="1" />
  </joint>
</robot>

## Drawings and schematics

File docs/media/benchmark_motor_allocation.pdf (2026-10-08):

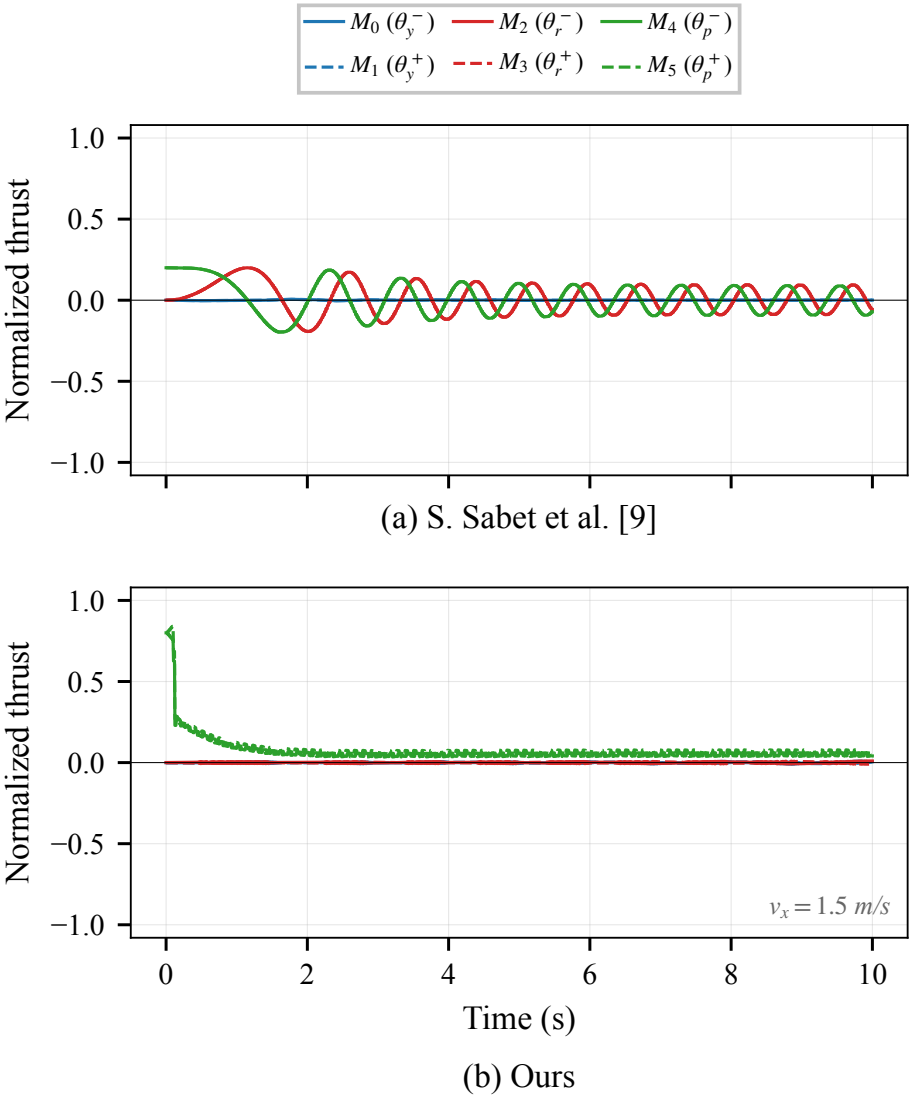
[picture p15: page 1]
Normalized thrust; Time (s); (b) Ours

(a) S. Sabet et al. [9]

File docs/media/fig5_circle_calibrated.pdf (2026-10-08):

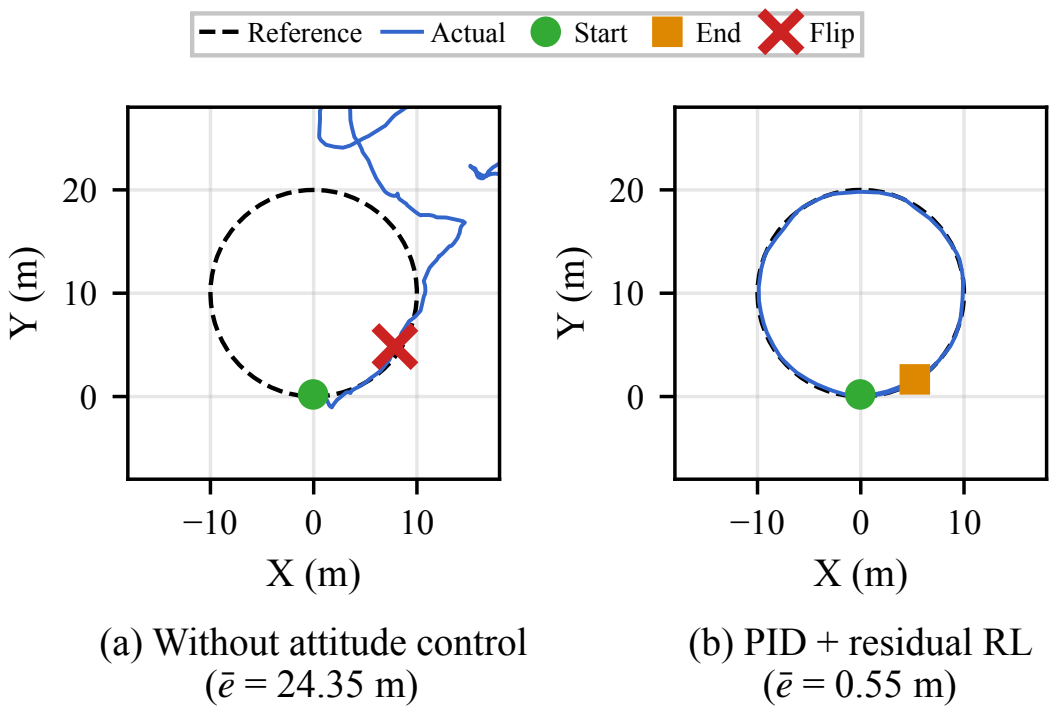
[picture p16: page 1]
(b) PID + residual RL (ē= 0.55 m); Reference; Actual; Start; End; Flip

(a) Without attitude control

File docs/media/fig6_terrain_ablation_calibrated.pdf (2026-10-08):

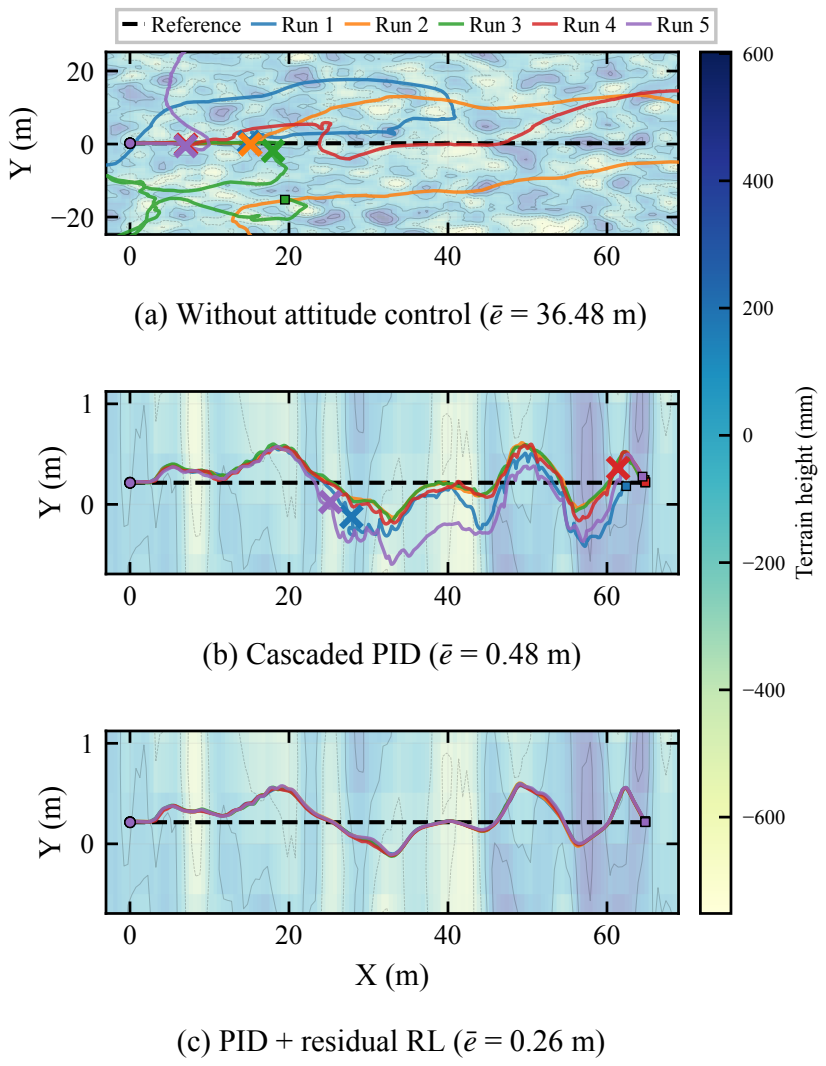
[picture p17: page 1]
(b) Cascaded PID (ē= 0.48 m); Reference; Run 1; Run 2; Run 3; Run 4; Run 5

(a) Without attitude control (ē= 36.48 m)

Terrain height (mm)

(c) PID + residual RL (ē= 0.26 m)

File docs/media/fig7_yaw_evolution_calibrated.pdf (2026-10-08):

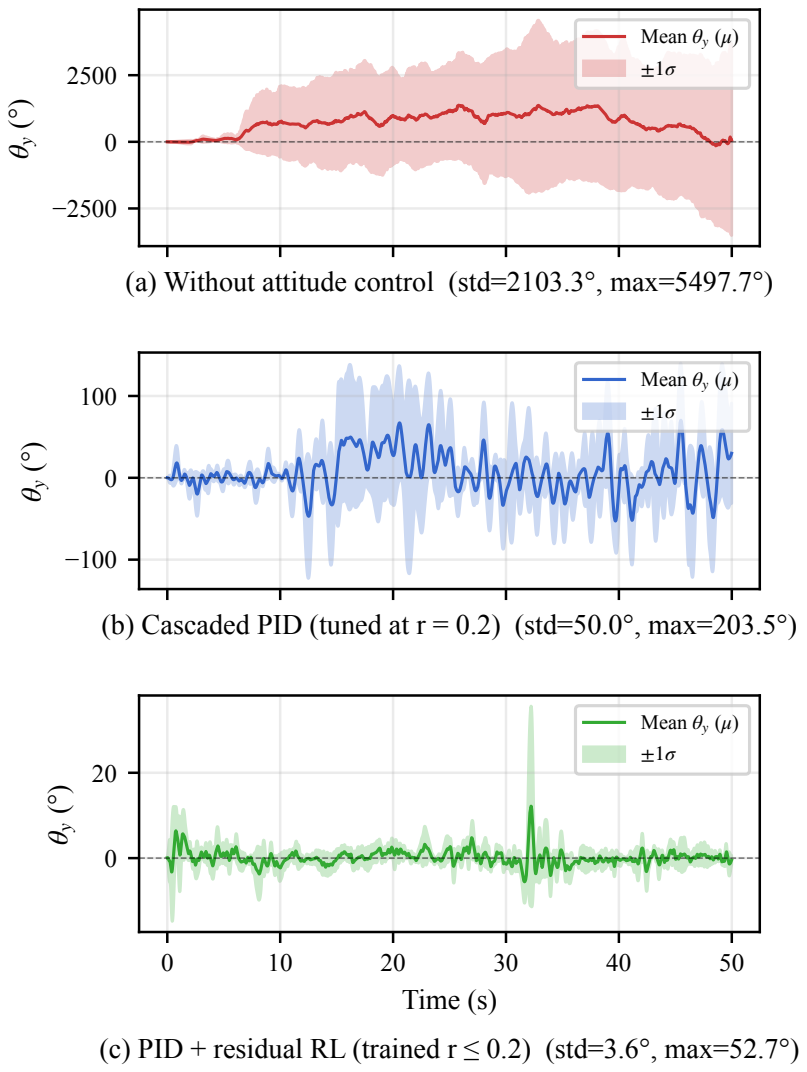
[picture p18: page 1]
Mean θy (μ) ±1σ; Time (s)

(a) Without attitude control (std=2103.3°, max=5497.7°)

Mean θy (μ)
±1σ

(b) Cascaded PID (tuned at r = 0.2) (std=50.0°, max=203.5°)

(c) PID + residual RL (trained r ≤ 0.2) (std=3.6°, max=52.7°)

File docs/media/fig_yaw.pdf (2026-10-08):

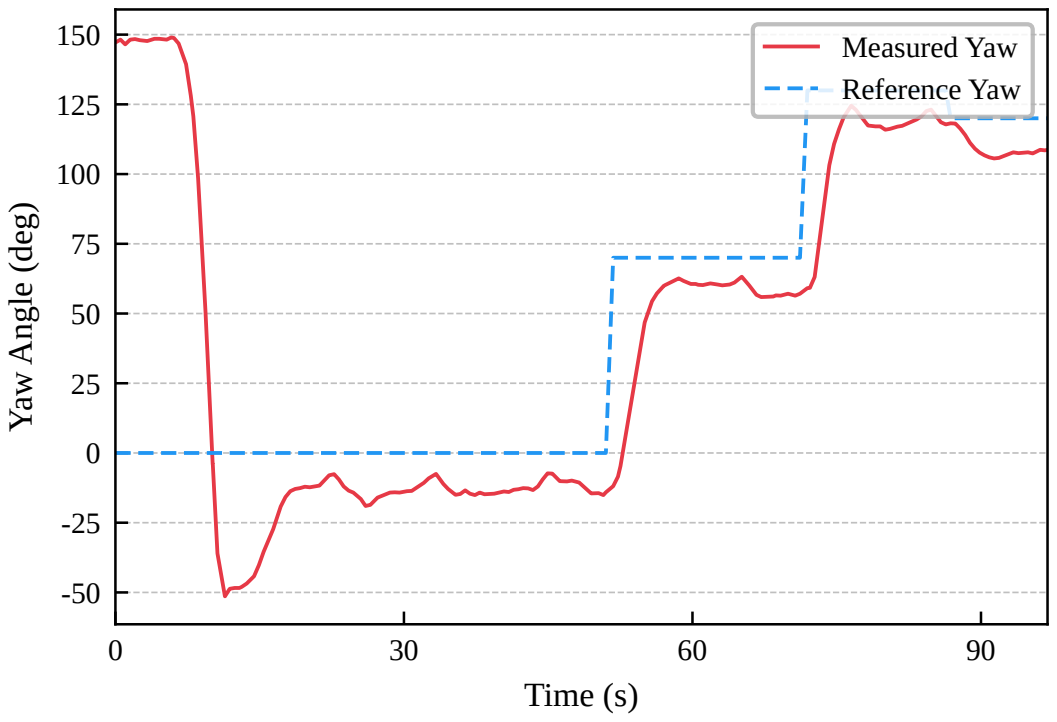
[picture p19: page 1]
Time (s); Measured Yaw Reference Yaw

Yaw Angle (deg)

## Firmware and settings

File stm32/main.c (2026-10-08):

#include <string.h>
#include <stdio.h>
#include <stdlib.h>

#include "FreeRTOS.h"
#include "task.h"
#include "queue.h"
#include "semphr.h"
#include "math.h"

#include <libopencm3/stm32/rcc.h>
#include <libopencm3/stm32/gpio.h>
#include <libopencm3/stm32/usart.h>
#include <libopencm3/stm32/timer.h>
#include <libopencm3/cm3/nvic.h>

#include "pin_config.h"
#include "uart_comm.h"
#include "motor_control.h"
#include "imu_reader.h"
#include "pid_control.h"
#include "motor_calibration.h"
#include "axis_stabilizer.h"      // 新的统一稳定器框架
#include "motion_controller.h"    // 运动控制器
#include "motor_calibration.h"    // 轴配置参数
#include "cascaded_pid.h"         // Yaw轴双环PID控制器

// 旧接口 (可选)
// #include "roll_stabilizer.h"
// #include "pitch_stabilizer.h"

#define TASK_PRIORITY_HIGH      (configMAX_PRIORITIES - 1)
#define TASK_PRIORITY_NORMAL    (configMAX_PRIORITIES - 2)
#define TASK_PRIORITY_LOW       (configMAX_PRIORITIES - 3)

static QueueHandle_t motor_cmd_queue;
static QueueHandle_t imu_data_queue;
QueueHandle_t uart_tx_queue;

// =====================================================
// 全局稳定器实例 (新框架)
// =====================================================
static AxisStabilizer g_roll_stabilizer;   // Roll轴稳定器 (Y方向运动)
static AxisStabilizer g_pitch_stabilizer;  // Pitch轴稳定器 (X方向运动)
static AxisStabilizer g_yaw_stabilizer;    // Yaw轴稳定器 (角度稳定, 单环PID - 已废弃)

// Yaw轴双环PID控制器 (新实现,替代单环g_yaw_stabilizer)
static CascadedPIDController g_yaw_cascaded_pid;

// Pitch轴双环PID控制器 (新实现,替代被动偏移控制)
static CascadedPIDController g_pitch_cascaded_pid;
typedef struct {
    uint16_t motor_pwm[6];      /* 6个电机PWM值 */
    float imu_data[11];          /* IMU数据: Rollv, Pitchv, Yawv, Roll, Pitch, Yaw, qw, qx, qy, qz */
    pid_params_t pid_params;    /* PID参数 */
    bool pid_enabled;           /* PID使能状态 */
    bool system_ready;          /* 系统就绪状态 */
} system_state_t;

// 全局系统状态 (供其他模块访问 IMU 数据)
system_state_t sys_state = {
    .motor_pwm = {PWM_CENTER_PULSE, PWM_CENTER_PULSE, PWM_CENTER_PULSE, 
                  PWM_CENTER_PULSE, PWM_CENTER_PULSE, PWM_CENTER_PULSE},
    .pid_params = {1.0f, 0.1f, 0.05f},
    .pid_enabled = false,
    .system_ready = false
};

// 硬件初始化
static void hardware_init(void) {
    /* 系统时钟配置 */
    rcc_clock_setup_pll(&rcc_hse_8mhz_3v3[RCC_CLOCK_3V3_168MHZ]);
    
    /* LED初始化 - F407 */
    rcc_periph_clock_enable(LED_RCC);
    gpio_mode_setup(LED_PORT, GPIO_MODE_OUTPUT, GPIO_PUPD_NONE, LED_PIN);
    gpio_set_output_options(LED_PORT, GPIO_OTYPE_PP, GPIO_OSPEED_2MHZ, LED_PIN);
    gpio_clear(LED_PORT, LED_PIN);  /* LED关闭 */
    // gpio_set(LED_PORT, LED_PIN);
}

static void uart_comm_task(void *args) {
    (void)args;
    
    uart_comm_init();
    
    char rx_buffer[128];
    char tx_buffer[128];
    int len;
    
    for (;;) {
        if ((len = uart_receive_line(RPI_UART, rx_buffer, sizeof(rx_buffer))) > 0) {
            if (strncmp(rx_buffer, "PWM:", 4) == 0) {                
                uint16_t pwm_values[6];
                if (parse_pwm_command(rx_buffer + 4, pwm_values) == 6) {
                    /* 发送到电机控制队列 */
                    xQueueSend(motor_cmd_queue, pwm_values, 0);
                    
                    snprintf(tx_buffer, sizeof(tx_buffer), 
                            "DEBUG:PWM command received, the second value is %d\n",
                            pwm_values[1]);
                    xQueueSend(uart_tx_queue, tx_buffer, 0);
                }
            }
            else if (strncmp(rx_buffer, "GPIOTEST", 8) == 0) {
                /* GPIO引脚测试命令 */
                motor_gpio_test();
                snprintf(tx_buffer, sizeof(tx_buffer), "GPIO Test executed\n");
                xQueueSend(uart_tx_queue, tx_buffer, 0);
            }
            else if (strncmp(rx_buffer, "PWMRESTORE", 10) == 0) {
                /* PWM模式恢复命令 */
                motor_pwm_restore();
                snprintf(tx_buffer, sizeof(tx_buffer), "PWM mode restored\n");
                xQueueSend(uart_tx_queue, tx_buffer, 0);
            }
            else if (strncmp(rx_buffer, "SMOOTH:", 7) == 0) {
                /* 平滑控制开关命令 SMOOTH:1 或 SMOOTH:0 */
                // int enable = atoi(rx_buffer + 7);
                // motor_set_smooth_enabled(enable != 0);
                // snprintf(tx_buffer, sizeof(tx_buffer),
                //         "DEBUG:Smooth mode %s\n",
                //         enable ? "enabled" : "disabled");
                // xQueueSend(uart_tx_queue, tx_buffer, 0);
            }
            else if (strncmp(rx_buffer, "YSTAB:", 6) == 0) {
                /* Y轴(Roll)稳定器开关命令 YSTAB:1 或 YSTAB:0 */
                int enable = atoi(rx_buffer + 6);
                // y_stab_set_enabled(enable != 0);  // 旧接口,已弃用
                axis_stabilizer_set_enabled(&g_roll_stabilizer, enable != 0);
                snprintf(tx_buffer, sizeof(tx_buffer),
                        "DEBUG:Roll stabilizer %s\n",
                        enable ? "enabled" : "disabled");
                xQueueSend(uart_tx_queue, tx_buffer, 0);
            }
            else if (strncmp(rx_buffer, "XSTAB:", 6) == 0) {
                /* X轴(Pitch)稳定器开关命令 XSTAB:1 或 XSTAB:0 */
                int enable = atoi(rx_buffer + 6);
                // 使用新的双环级联PID控制器
                cascaded_pid_set_enabled(&g_pitch_cascaded_pid, enable != 0);
                snprintf(tx_buffer, sizeof(tx_buffer),
                        "DEBUG:Pitch cascaded PID %s\n",
                        enable ? "enabled" : "disabled");
                xQueueSend(uart_tx_queue, tx_buffer, 0);
            }
            else if (strncmp(rx_buffer, "XDEBUG:", 7) == 0) {
                /* Pitch调试输出开关命令 XDEBUG:1 或 XDEBUG:0 */
                int enable = atoi(rx_buffer + 7);
                cascaded_pid_set_debug_enabled(&g_pitch_cascaded_pid, enable != 0);
                snprintf(tx_buffer, sizeof(tx_buffer),
                        "DEBUG:Pitch debug output %s\n",
                        enable ? "enabled" : "disabled");
                xQueueSend(uart_tx_queue, tx_buffer, 0);
            }
            else if (strncmp(rx_buffer, "ZSTAB:", 6) == 0) {
                /* Yaw轴稳定器开关命令 ZSTAB:1 或 ZSTAB:0 */
                int enable = atoi(rx_buffer + 6);
                cascaded_pid_set_enabled(&g_yaw_cascaded_pid, enable != 0);
                snprintf(tx_buffer, sizeof(tx_buffer),
                        "DEBUG:Yaw cascaded PID %s\n",
                        enable ? "enabled" : "disabled");
                xQueueSend(uart_tx_queue, tx_buffer, 0);
            }
            else if (strncmp(rx_buffer, "ZDEBUG:", 7) == 0) {
                /* Yaw调试输出开关命令 ZDEBUG:1 或 ZDEBUG:0 */
                int enable = atoi(rx_buffer + 7);
                cascaded_pid_set_debug_enabled(&g_yaw_cascaded_pid, enable != 0);
                snprintf(tx_buffer, sizeof(tx_buffer),
                        "DEBUG:Yaw debug output %s\n",
                        enable ? "enabled" : "disabled");
                xQueueSend(uart_tx_queue, tx_buffer, 0);
            }
            else if (strncmp(rx_buffer, "MOTION:", 7) == 0) {
                /* 运动控制命令 MOTION:vx,vy  范围:-1.0~+1.0 */
                float vx, vy;
                if (sscanf(rx_buffer + 7, "%f,%f", &vx, &vy) == 2) {
                    motion_set_velocity(vx, vy);
                    snprintf(tx_buffer, sizeof(tx_buffer),
                            "DEBUG:Motion velocity set: vx=%.2f, vy=%.2f\n",
                            vx, vy);
                    xQueueSend(uart_tx_queue, tx_buffer, 0);
                }
            }
            else if (strncmp(rx_buffer, "MOTIONSTOP", 10) == 0) {
                /* 停止运动命令 */
                motion_stop();
                snprintf(tx_buffer, sizeof(tx_buffer),
                        "DEBUG:Motion stopped\n");
                xQueueSend(uart_tx_queue, tx_buffer, 0);
            }
            else if (strncmp(rx_buffer, "PID:", 4) == 0) {
                /* PID参数设置 */
                float kp, ki, kd;
                if (sscanf(rx_buffer + 4, "%f,%f,%f", &kp, &ki, &kd) == 3) {
                    sys_state.pid_params.kp = kp;
                    sys_state.pid_params.ki = ki;
                    sys_state.pid_params.kd = kd;
                    
                    snprintf(tx_buffer, sizeof(tx_buffer), 
                            "DEBUG:PID params updated: %.2f,%.2f,%.2f\n", 
                            kp, ki, kd);
                    xQueueSend(uart_tx_queue, tx_buffer, 0);
                }
            }
            else if (strncmp(rx_buffer, "IMU", 3) == 0) {
                /* IMU数据请求 */
                snprintf(tx_buffer, sizeof(tx_buffer), 
                        "IMU:%.3f,%.3f,%.3f,%.3f,%.3f,%.3f,%.3f,%.3f,%.3f,%.3f\n",
                        sys_state.imu_data[0], sys_state.imu_data[1], sys_state.imu_data[2], 
                        sys_state.imu_data[3], sys_state.imu_data[4], sys_state.imu_data[5],
                        sys_state.imu_data[6], sys_state.imu_data[7], sys_state.imu_data[8], 
                        sys_state.imu_data[9]);

                gpio_toggle(LED_PORT, LED_PIN);
                uart_send_string(RPI_UART, tx_buffer);
            }
            else if (strncmp(rx_buffer, "STABLE:", 7) == 0) {
                /* 运行时设置stable角度: STABLE:<axis>,<angle> 例如 STABLE:Roll,30 */
                char axis_name[16];
                float angle_deg;
                if (sscanf(rx_buffer + 7, "%15[^,],%f", axis_name, &angle_deg) == 2) {
                    if (motor_set_target_angle(axis_name, angle_deg)) {
                        snprintf(tx_buffer, sizeof(tx_buffer), "DEBUG:TARGET %s set to %.2f\n", axis_name, angle_deg);
                    } else {
                        snprintf(tx_buffer, sizeof(tx_buffer), "ERROR:Unknown axis %s\n", axis_name);
                    }
                } else {
                    snprintf(tx_buffer, sizeof(tx_buffer), "ERROR:Invalid STABLE format, use STABLE:<axis>,<angle>\n");
                }
                xQueueSend(uart_tx_queue, tx_buffer, 0);
            }
            else if (strncmp(rx_buffer, "GET_STABLE:", 11) == 0) {
                /* 查询target角度: GET_STABLE:<axis> 例如 GET_STABLE:Roll */
                char axis_name[16];
                if (sscanf(rx_buffer + 11, "%15s", axis_name) == 1) {
                    float angle;
                    if (motor_get_target_angle(axis_name, &angle)) {
                        snprintf(tx_buffer, sizeof(tx_buffer), "STABLE:%s,%.2f\n", axis_name, angle);
                    } else {
                        snprintf(tx_buffer, sizeof(tx_buffer), "ERROR:Unknown axis %s\n", axis_name);
                    }
                } else {
                    snprintf(tx_buffer, sizeof(tx_buffer), "ERROR:Invalid GET_STABLE format, use GET_STABLE:<axis>\n");
                }
                xQueueSend(uart_tx_queue, tx_buffer, 0);
            }
            else if (strncmp(rx_buffer, "STATUS", 6) == 0) {
                /* 系统状态查询 */
                snprintf(tx_buffer, sizeof(tx_buffer), 
                        "STATUS:%d,%d,%d\n",
                        sys_state.system_ready ? 1 : 0,
                        1,  /* IMU状态 */
                        sys_state.pid_enabled ? 1 : 0);
            
                uart_send_string(RPI_UART, tx_buffer);
                gpio_toggle(LED_PORT, LED_PIN);
                // uart_send_string(RPI_UART, "A");
            }
        }
        
        if (xQueueReceive(uart_tx_queue, tx_buffer, 10) == pdPASS) {
            uart_send_string(RPI_UART, tx_buffer);
        }
        
        vTaskDelay(pdMS_TO_TICKS(10));
        gpio_toggle(LED_PORT, LED_PIN);
    }
}

/*********************************************************************
 * 电机控制任务
 *********************************************************************/
static void motor_control_task(void *args) {
    (void)args;

    motor_control_init();

    uint16_t motor_pwm[6];

    for (;;) {
        /* 接收PWM命令（非阻塞，使用超时） */
        if (xQueueReceive(motor_cmd_queue, motor_pwm, pdMS_TO_TICKS(10)) == pdPASS) {
            /* 更新目标PWM值 */
            for (int i = 0; i < 6; i++) {
                sys_state.motor_pwm[i] = motor_pwm[i];
            }

            
            motor_set_all_pwm(motor_pwm);
        

            /* LED指示 */
            gpio_toggle(LED_PORT, LED_PIN);
        }

        /* 平滑更新已禁用，由稳定器直接控制电机 */
        // motor_update_smooth();

        /* 控制周期延时 */
        vTaskDelay(pdMS_TO_TICKS(10));  /* 100Hz控制频率 */
    }
}

/*********************************************************************
 * IMU数据读取任务
 *********************************************************************/
static void imu_reader_task(void *args) {
    (void)args;
    
    imu_reader_init();
    
    imu_data_t imu_data;
    
    for (;;) {
        /* 读取IMU数据 */

        if (imu_read_data(&imu_data) == 0) {
            /* 更新全局状态 */
            sys_state.imu_data[0] = imu_data.RollSpeed;
            sys_state.imu_data[1] = imu_data.PitchSpeed;
            sys_state.imu_data[2] = imu_data.YawSpeed;
            sys_state.imu_data[3] = imu_data.Roll;
            sys_state.imu_data[4] = imu_data.Pitch;
            // sys_state.imu_data[5] = imu_data.Yaw;
            sys_state.imu_data[6] = imu_data.qw;
            sys_state.imu_data[7] = imu_data.qx;
            sys_state.imu_data[8] = imu_data.qy;
            sys_state.imu_data[9] = imu_data.qz;
            sys_state.imu_data[10] = imu_data.timestamp; 
            float qw = imu_data.qw;
            float qx = imu_data.qx;
            float qy = imu_data.qy;
            float qz = imu_data.qz;
            sys_state.imu_data[5] = atan2f(2.0f * (qw * qz + qx * qy), 1.0f - 2.0f * (qy * qy + qz * qz)) * 57.29578f;
            
            char msg[50];
            // snprintf(msg, sizeof(msg), "Roll:%.2f Pitch:%.2f Yaw:%.2f", 
            //          imu_data.Roll, imu_data.Pitch, imu_data.Yaw);
            // xQueueSend(uart_tx_queue, msg, 0);
 
        }else{
            char* msgg= get_imu_status();
            xQueueSend(uart_tx_queue, msgg, 0);
        }
        
        vTaskDelay(pdMS_TO_TICKS(10));  /* 10Hz采样 */
    }
}

/*********************************************************************
 * PID控制任务
 *********************************************************************/
static void pid_control_task(void *args) {
    (void)args;
    
    pid_init(&sys_state.pid_params);
    
    imu_data_t imu_data;
    uint16_t motor_corrections[6];
    
    for (;;) {
        if (sys_state.pid_enabled && 
            xQueueReceive(imu_data_queue, &imu_data, 100) == pdPASS) {
            
            pid_calculate(&imu_data, sys_state.motor_pwm, motor_corrections);
            
            xQueueSend(motor_cmd_queue, motor_corrections, 0);
        }
        
        vTaskDelay(pdMS_TO_TICKS(20));  /* 100Hz控制频率 */
    }
}

/*********************************************************************
 * 系统监控任务
 *********************************************************************/
static void system_monitor_task(void *args) {
    (void)args;
    char debug_msg[64];
    
    for (;;) {
        /* 系统状态检查 */
        sys_state.system_ready = true;
        
        /* 定期发送系统信息 */
        snprintf(debug_msg, sizeof(debug_msg), 
                "DEBUG:System running, free heap: %u\n", 
                xPortGetFreeHeapSize());
        xQueueSend(uart_tx_queue, debug_msg, 0);
        
        vTaskDelay(pdMS_TO_TICKS(1000)); 
    }
}
static int counter_for_debug = 0;
static void SendDebugProcess(void *args){
    (void)args;
    
    for (;;) {
        counter_for_debug ++;
        char send_buffer[64];  // 减小缓冲区
        snprintf(send_buffer, sizeof(send_buffer), 
                "Debug_msg sent from stm32! Counter: %\n", counter_for_debug);
        // 使用队列发送，避免直接UART冲突
        xQueueSend(uart_tx_queue, send_buffer, 0);
        vTaskDelay(pdMS_TO_TICKS(10000));  // 降低频率到10秒
    }
}

// static void y_axis_stab_task(void *args){
//     (void)args;
//     const float dt = 0.02f; // 20ms
//     for(;;){
//         stabilize_y_axis_step(dt);
//         vTaskDelay(pdMS_TO_TICKS(20));
//     }
// }

// static void x_axis_stab_task(void *args){
//     (void)args;
//     const float dt = 0.02f; // 20ms
//     for(;;){
//         stabilize_x_axis_step(dt);
//         vTaskDelay(pdMS_TO_TICKS(20));
//     }
// }

/*********************************************************************
 * 新框架稳定器任务
 *********************************************************************/
static void roll_stab_task_new(void *args) {
    (void)args;
    const float dt = 0.02f; // 20ms = 50Hz控制频率

    for (;;) {
        // 从motion_controller获取PWM偏移量并设置
        int16_t offset = motion_get_roll_pwm_offset();
        axis_stabilizer_set_pwm_offset(&g_roll_stabilizer, offset);

        // 执行控制步进
        axis_stabilizer_step(&g_roll_stabilizer, dt);

        vTaskDelay(pdMS_TO_TICKS(20));
    }
}

static void pitch_stab_task_new(void *args) {
    (void)args;

    for (;;) {
        if (g_pitch_cascaded_pid.enabled) {
            // 从motion_controller获取PWM偏移量并设置
            int16_t offset = motion_get_pitch_pwm_offset();
            cascaded_pid_set_pwm_offset(&g_pitch_cascaded_pid, offset);

            // 从PITCH_AXIS_CONFIG同步目标角度到cascaded PID控制器
            cascaded_pid_set_target_angle(&g_pitch_cascaded_pid,
                                          PITCH_AXIS_CONFIG.target_angle_deg);

            // 直接从全局 sys_state 读取 IMU 数据 (无阻塞)
            // sys_state.imu_data[4] = Pitch, sys_state.imu_data[1] = PitchSpeed
            float pitch_angle = sys_state.imu_data[4];
            float pitch_speed = sys_state.imu_data[1];

            // 执行双环PID控制
            cascaded_pid_step(&g_pitch_cascaded_pid, pitch_angle, pitch_speed);
        }
        // 禁用时不覆盖PWM,允许手动控制或其他任务设置

        vTaskDelay(pdMS_TO_TICKS(20));  // 50Hz
    }
}

static void yaw_stab_task_new(void *args) {
    (void)args;

    for (;;) {
        if (g_yaw_cascaded_pid.enabled) {
            // 获取motion_controller的偏移量 (保持兼容性)
            int16_t offset = motion_get_yaw_pwm_offset();
            cascaded_pid_set_pwm_offset(&g_yaw_cascaded_pid, offset);

            // 从YAW_AXIS_CONFIG同步目标角度到cascaded PID控制器
            cascaded_pid_set_target_angle(&g_yaw_cascaded_pid, YAW_AXIS_CONFIG.target_angle_deg);

            // 直接从全局 sys_state 读取 IMU 数据 (无阻塞)
            // sys_state.imu_data[5] = Yaw, sys_state.imu_data[2] = YawSpeed
            float yaw_angle = sys_state.imu_data[5];
            float yaw_speed = sys_state.imu_data[2];

            // 执行双环PID控制
            cascaded_pid_step(&g_yaw_cascaded_pid, yaw_angle, yaw_speed);
        }
        // 禁用时不覆盖PWM,允许手动控制或其他任务设置

        vTaskDelay(pdMS_TO_TICKS(20));  // 50Hz
    }
}

/*********************************************************************
 * FreeRTOS钩子函数
 *********************************************************************/
void vApplicationStackOverflowHook(TaskHandle_t xTask, char *pcTaskName) {
    (void)xTask;
    (void)pcTaskName;
    
    /* 栈溢出处理 - 停止系统 */
    for (;;) {
        gpio_set(LED_PORT, LED_PIN);    /* LED常亮 */
        vTaskDelay(pdMS_TO_TICKS(100));
        gpio_clear(LED_PORT, LED_PIN);
        vTaskDelay(pdMS_TO_TICKS(100));
    }
}

void vApplicationMallocFailedHook(void) {
    /* 内存分配失败处理 */
    for (;;) {
        gpio_set(LED_PORT, LED_PIN);    /* LED快闪 */
        vTaskDelay(pdMS_TO_TICKS(50));
        gpio_clear(LED_PORT, LED_PIN);
        vTaskDelay(pdMS_TO_TICKS(50));
    }
}

int main(void) {
    hardware_init();

    motor_cmd_queue = xQueueCreate(4, sizeof(uint16_t) * 6);
    imu_data_queue = xQueueCreate(4, sizeof(imu_data_t));
    uart_tx_queue = xQueueCreate(8, 128);

    uart_comm_init();

    /* 初始化运行时可调整的校准参数 */
    motor_calibration_init();

    // ===== 初始化新框架 =====
    // 初始化三个轴的稳定器
    axis_stabilizer_init(&g_roll_stabilizer, &ROLL_AXIS_CONFIG);
    axis_stabilizer_init(&g_pitch_stabilizer, &PITCH_AXIS_CONFIG);
    // axis_stabilizer_init(&g_yaw_stabilizer, &YAW_AXIS_CONFIG);  // 已废弃,使用双环PID

    // 初始化Yaw轴双环PID控制器 (替代单环g_yaw_stabilizer)
    // 电机索引: 0=neg, 1=pos
    cascaded_pid_init(&g_yaw_cascaded_pid, &YAW_CASCADED_PID_CONFIG, 0, 1);
    g_yaw_cascaded_pid.axis_name = "Yaw";

    // 初始化Pitch轴双环PID控制器 (替代被动偏移控制)
    // 电机索引: 4=neg, 5=pos
    cascaded_pid_init(&g_pitch_cascaded_pid, &PITCH_CASCADED_PID_CONFIG, 4, 5);
    g_pitch_cascaded_pid.axis_name = "Pitch";

    // 初始化运动控制器
    motion_controller_init();

    // 默认关闭稳定控制器
    axis_stabilizer_set_enabled(&g_roll_stabilizer, false);
    axis_stabilizer_set_enabled(&g_pitch_stabilizer, false);
    // axis_stabilizer_set_enabled(&g_yaw_stabilizer, false);  // 已废弃
    cascaded_pid_set_enabled(&g_yaw_cascaded_pid, false);    // Yaw双环PID默认关闭
    cascaded_pid_set_enabled(&g_pitch_cascaded_pid, false);  // Pitch双环PID默认关闭


    motion_set_enabled(true);

    /* 创建任务 */
    xTaskCreate(uart_comm_task, "UART", 500, NULL, TASK_PRIORITY_HIGH, NULL);
    xTaskCreate(motor_control_task, "MOTOR", 500, NULL, TASK_PRIORITY_NORMAL, NULL);
    xTaskCreate(imu_reader_task, "IMU", 500, NULL, TASK_PRIORITY_NORMAL, NULL);

    // ===== 选择使用新框架或旧框架 =====
    // 旧框架 (已弃用,可用于回退测试)
    // xTaskCreate(y_axis_stab_task, "YSTAB", 400, NULL, TASK_PRIORITY_NORMAL, NULL);
    // xTaskCreate(x_axis_stab_task, "XSTAB", 400, NULL, TASK_PRIORITY_NORMAL, NULL);

    xTaskCreate(roll_stab_task_new, "ROLL", 400, NULL, TASK_PRIORITY_NORMAL, NULL);
    xTaskCreate(pitch_stab_task_new, "PITCH", 400, NULL, TASK_PRIORITY_NORMAL, NULL);
    xTaskCreate(yaw_stab_task_new, "YAW", 400, NULL, TASK_PRIORITY_NORMAL, NULL);
    
    // xTaskCreate(pid_control_task, "PID", 100, NULL, TASK_PRIORITY_NORMAL, NULL);
    // xTaskCreate(system_monitor_task, "MONITOR", 100, NULL, TASK_PRIORITY_LOW, NULL);

    vTaskStartScheduler();
    for (;;);
    return 0;
}

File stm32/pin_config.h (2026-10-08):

#ifndef PIN_CONFIG_H
#define PIN_CONFIG_H

#include <libopencm3/stm32/gpio.h>
#include <libopencm3/stm32/rcc.h>
#include <libopencm3/stm32/timer.h>
#include <libopencm3/stm32/usart.h>

/* 目标硬件: STM32F407VET6 (唯一支持的平台) */
    #define SYSTEM_CLOCK_HZ     168000000
    
    /* LED - PD12 (板载LED) */
    #define LED_PORT            GPIOD
    #define LED_PIN             GPIO12
    #define LED_RCC             RCC_GPIOD
    
    /* 树莓派通信 - USART1 (PA9/PA10) */
    #define RPI_UART            USART1
    #define RPI_UART_RCC        RCC_USART1
    #define RPI_UART_GPIO_RCC   RCC_GPIOA
    #define RPI_UART_PORT       GPIOA
    #define RPI_UART_TX_PIN     GPIO9
    #define RPI_UART_RX_PIN     GPIO10
    
    /* IMU通信 - USART2 (PA2/PA3) */
    #define IMU_UART            USART2
    #define IMU_UART_RCC        RCC_USART2
    #define IMU_UART_GPIO_RCC   RCC_GPIOA
    #define IMU_UART_PORT       GPIOA
    #define IMU_UART_TX_PIN     GPIO2
    #define IMU_UART_RX_PIN     GPIO3
    
    /* 6个电机PWM配置 - 使用TIM3/TIM4避开FSMC冲突 */
    
    /* 电机1: TIM3_CH1, PC6 */
    #define MOTOR1_TIM          TIM3
    #define MOTOR1_TIM_RCC      RCC_TIM3
    #define MOTOR1_CH           TIM_OC1
    #define MOTOR1_PORT         GPIOC
    #define MOTOR1_GPIO_RCC     RCC_GPIOC
    #define MOTOR1_PIN          GPIO6
    #define MOTOR1_AF           GPIO_AF2
    
    /* 电机2: TIM3_CH2, PC7 */
    #define MOTOR2_TIM          TIM3
    #define MOTOR2_TIM_RCC      RCC_TIM3
    #define MOTOR2_CH           TIM_OC2
    #define MOTOR2_PORT         GPIOC
    #define MOTOR2_GPIO_RCC     RCC_GPIOC
    #define MOTOR2_PIN          GPIO7
    #define MOTOR2_AF           GPIO_AF2
    
    /* 电机3: TIM3_CH3, PC8 */
    #define MOTOR3_TIM          TIM3
    #define MOTOR3_TIM_RCC      RCC_TIM3
    #define MOTOR3_CH           TIM_OC3
    #define MOTOR3_PORT         GPIOC
    #define MOTOR3_GPIO_RCC     RCC_GPIOC
    #define MOTOR3_PIN          GPIO8
    #define MOTOR3_AF           GPIO_AF2
    
    /* 电机4: TIM3_CH4, PC9 */
    #define MOTOR4_TIM          TIM3
    #define MOTOR4_TIM_RCC      RCC_TIM3
    #define MOTOR4_CH           TIM_OC4
    #define MOTOR4_PORT         GPIOC
    #define MOTOR4_GPIO_RCC     RCC_GPIOC
    #define MOTOR4_PIN          GPIO9
    #define MOTOR4_AF           GPIO_AF2
    
    /* 电机5: TIM4_CH1, PB6 */
    #define MOTOR5_TIM          TIM4
    #define MOTOR5_TIM_RCC      RCC_TIM4
    #define MOTOR5_CH           TIM_OC1
    #define MOTOR5_PORT         GPIOB
    #define MOTOR5_GPIO_RCC     RCC_GPIOB
    #define MOTOR5_PIN          GPIO6
    #define MOTOR5_AF           GPIO_AF2
    
    /* 电机6: TIM4_CH2, PB7 */
    #define MOTOR6_TIM          TIM4
    #define MOTOR6_TIM_RCC      RCC_TIM4
    #define MOTOR6_CH           TIM_OC2
    #define MOTOR6_PORT         GPIOB
    #define MOTOR6_GPIO_RCC     RCC_GPIOB
    #define MOTOR6_PIN          GPIO7
    #define MOTOR6_AF           GPIO_AF2


#define PWM_FREQUENCY_HZ    50      /* 50Hz for ESCs - 无刷电调标准频率 */

  #define TIMER_CLOCK_HZ      84000000
  #define PWM_PRESCALER       (TIMER_CLOCK_HZ / 1000000)  /* 84: 1MHz时基 */

#define PWM_PERIOD          20000  
#define PWM_MIN_PULSE       1350    
#define PWM_MAX_PULSE       1650   
#define PWM_CENTER_PULSE    1500    

#define RPI_UART_BAUDRATE   115200
#define IMU_UART_BAUDRATE   115200

#endif

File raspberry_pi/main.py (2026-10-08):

import serial
import time
import threading
import multiprocessing
import json
import os
from typing import List, Optional, Dict, Any
import paho.mqtt.client as mqtt
import logging
from collections import deque
import numpy as np
from datetime import datetime


def _plot_in_process(plot_func_name: str, data_dict: dict, plot_save_dir: str, extra_args: dict = None):
    """
    在独立进程中执行绘图，避免matplotlib多线程竞争问题

    Args:
        plot_func_name: 绘图函数名称 ('roll', 'pitch', 'pitch_cascaded', 'yaw')
        data_dict: 数据字典（从deque转换而来）
        plot_save_dir: 图片保存目录
        extra_args: 额外参数
    """
    # 在子进程中导入matplotlib，确保每个进程有独立的实例
    import matplotlib
    matplotlib.use('Agg')
    import matplotlib.pyplot as plt

    try:
        if plot_func_name == 'roll':
            _plot_roll_stabilizer(data_dict, plot_save_dir)
        elif plot_func_name == 'pitch_cascaded':
            _plot_pitch_cascaded(data_dict, plot_save_dir)
        elif plot_func_name == 'yaw':
            _plot_yaw_cascaded(data_dict, plot_save_dir)
    except Exception as e:
        print(f"[绘图错误] {plot_func_name}: {e}")


def _plot_roll_stabilizer(data_dict: dict, plot_save_dir: str):
    """Roll轴单环PID绘图（在独立进程中执行）"""
    import matplotlib.pyplot as plt

    if len(data_dict['timestamp']) < 10:
        print("[警告] Roll轴数据点太少，跳过绘图")
        return

    t = np.array(data_dict['timestamp'])
    angle = np.array(data_dict['roll'])
    error = np.array(data_dict['error'])
    pid_control = np.array(data_dict['pid_control'])
    gravity_comp = np.array(data_dict['gravity_comp'])
    control = np.array(data_dict['control'])
    feedforward = np.array(data_dict['feedforward'])
    delta = np.array(data_dict['delta'])
    motor2 = np.array(data_dict['motor2'])
    motor3 = np.array(data_dict['motor3'])

    fig, axes = plt.subplots(5, 1, figsize=(14, 15))
    fig.suptitle(f'Roll-Axis Stabilizer Performance Analysis\n'
                f'Data points: {len(t)}, Duration: {t[-1]:.1f}s',
                fontsize=14, fontweight='bold')

    # 子图1: 角度和误差
    ax1 = axes[0]
    ax1.plot(t, angle, 'b-', linewidth=1.5, label='Roll Angle', alpha=0.8)
    ax1.axhline(y=0, color='k', linestyle='--', linewidth=0.8, alpha=0.5)
    ax1.plot(t, error, 'r-', linewidth=1, label='Error', alpha=0.7)
    ax1.set_ylabel('Angle (degrees)', fontsize=11)
    ax1.legend(loc='upper right', fontsize=10)
    ax1.grid(True, alpha=0.3)
    ax1.set_title('Roll Angle & Error', fontsize=12, fontweight='bold')

    # 子图2: PID控制 vs 重力补偿
    ax2 = axes[1]
    ax2.plot(t, pid_control, 'g-', linewidth=1.5, label='PID Control (u_pid)', alpha=0.8)
    ax2.plot(t, gravity_comp, 'orange', linewidth=1.5, label='Gravity Compensation (grav)', alpha=0.8)
    ax2.plot(t, control, 'b--', linewidth=1, label='Total Control (u_total)', alpha=0.6)
    ax2.axhline(y=0, color='k', linestyle='--', linewidth=0.8, alpha=0.5)
    ax2.set_ylabel('Control Value', fontsize=11)
    ax2.legend(loc='upper right', fontsize=10)
    ax2.grid(True, alpha=0.3)
    ax2.set_title('Control Components: PID vs Gravity Compensation', fontsize=12, fontweight='bold')

    # 子图3: 总控制量和前馈
    ax3 = axes[2]
    ax3.plot(t, control, 'g-', linewidth=1.5, label='Total Control (u)', alpha=0.8)
    ax3.plot(t, feedforward, 'm-', linewidth=1.2, label='Feedforward (ff)', alpha=0.7)
    ax3.axhline(y=0, color='k', linestyle='--', linewidth=0.8, alpha=0.5)
    ax3.set_ylabel('Control Value', fontsize=11)
    ax3.legend(loc='upper right', fontsize=10)
    ax3.grid(True, alpha=0.3)
    ax3.set_title('Total Control & Feedforward', fontsize=12, fontweight='bold')

    # 子图4: Delta (PWM调整量)
    ax4 = axes[3]
    ax4.plot(t, delta, 'c-', linewidth=1.5, label='Delta (PWM adjustment)', alpha=0.8)
    ax4.axhline(y=0, color='k', linestyle='--', linewidth=0.8, alpha=0.5)
    ax4.set_ylabel('Delta (PWM units)', fontsize=11)
    ax4.legend(loc='upper right', fontsize=10)
    ax4.grid(True, alpha=0.3)
    ax4.set_title('PWM Adjustment Delta', fontsize=12, fontweight='bold')

    # 子图5: 电机PWM值
    ax5 = axes[4]
    ax5.plot(t, motor2, 'orange', linewidth=1.5, label='Motor M2 PWM', alpha=0.8)
    ax5.plot(t, motor3, 'purple', linewidth=1.5, label='Motor M3 PWM', alpha=0.8)
    ax5.axhline(y=1500, color='k', linestyle='--', linewidth=0.8, alpha=0.5, label='Neutral (1500)')
    ax5.set_xlabel('Time (seconds)', fontsize=11)
    ax5.set_ylabel('PWM Value', fontsize=11)
    ax5.legend(loc='upper right', fontsize=10)
    ax5.grid(True, alpha=0.3)
    ax5.set_title('Motor PWM Output (Roll: M2, M3)', fontsize=12, fontweight='bold')
    ax5.set_ylim([1300, 1700])

    plt.tight_layout()

    timestamp_str = datetime.now().strftime('%Y%m%d_%H%M%S')
    filename = f'roll_stab_analysis_{timestamp_str}.png'
    filepath = os.path.join(plot_save_dir, filename)

    plt.savefig(filepath, dpi=150, bbox_inches='tight')
    plt.close(fig)

    print(f"\n[绘图] Roll轴稳定器数据分析图已保存: {filepath}")
    print(f"       数据点: {len(t)}, 持续时间: {t[-1]:.1f}秒\n")
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

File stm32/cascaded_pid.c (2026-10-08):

/*
 * 双环级联PID控制器实现
 *
 * 控制流程:
 * 1. 外环 (位置环): 角度误差 → 速度目标
 * 2. 内环 (速度环): 速度误差 → PWM增量
 * 3. PWM输出: 基准PWM + 增量*符号 + 外部偏移
 *
 * ============================================================================
 * FIXME (kinematic coupling — to be fixed, see branch `test_jacobian`)
 * ============================================================================
 * 当前在 motion_controller.c 中对 roll / pitch / yaw 三个轴各自独立调用
 * cascaded_pid_step()，外环输出的速度目标被直接当作内环要跟踪的目标，并与
 * IMU 测得的体坐标系角速度做差。这一做法忽略了欧拉角速率与体坐标系角速度
 * 之间的运动学耦合：
 *
 *     omega_body = E(phi, theta) * [r_dot, p_dot, y_dot]^T
 *
 *     E(phi, theta) =
 *         [[1,    0,         -sin(theta)              ],
 *          [0,    cos(phi),   sin(phi)*cos(theta)     ],
 *          [0,   -sin(phi),   cos(phi)*cos(theta)     ]]
 *
 *     phi = roll, theta = pitch
 *
 * 仅当 phi ~= theta ~= 0 时 E ~= I，独立轴 PID 才近似成立。当机器人显著倾斜
 * 时，三轴控制目标会出现串扰，姿态稳定与跟踪精度下降。
 *
 * 仿真侧 (simulation/mujoco_sim/control/cascaded_pid.py) 已存在等价的 FIXME
 * 与对应修复方案，详见 `test_jacobian` 分支。固件侧需要同步重构：
 *   1. 拆分 cascaded_pid_step() 为 cascaded_pid_outer_step() 与
 *      cascaded_pid_inner_step()。
 *   2. 在 motion_controller.c 中插入欧拉速率到体角速率的 E 变换。
 *   3. PID 增益需要重新整定。
 * ============================================================================
 */

#include "cascaded_pid.h"
#include "motor_control.h"
#include "FreeRTOS.h"
#include "queue.h"
#include <math.h>
#include <stdio.h>
#include <string.h>

// ===== 常量定义 =====

// 微分滤波系数 (低通滤波)
#define D_FILTER_ALPHA  0.2f

// PWM速率限制 (防止突变)
#define PWM_SLEW_RATE   10

// 外环输出(速度目标)速率限制 (°/s per step)
#define VELOCITY_TARGET_SLEW_RATE  5.0f

// 外环积分限幅
#define OUTER_INTEGRAL_LIMIT  100.0f

// 内环积分限幅
#define INNER_INTEGRAL_LIMIT  100.0f

// 调试输出频率分频 (每N次输出一次)
#define DEBUG_OUTPUT_DIVIDER  25

// 角度转弧度
#define DEG2RAD  0.017453292f
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
